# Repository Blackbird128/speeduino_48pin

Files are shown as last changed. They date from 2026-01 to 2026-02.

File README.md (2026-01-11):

# speeduino_48pin
Custom speeduino v0.4.4d hardware made to fit a standard housing with dual 24-pin Delphi connectors.

Simpler and lower cost alternative to the Speeduino Dropbear while keeping the same form factor and full compatibility with the Speeduino v0.4.4d hardware.

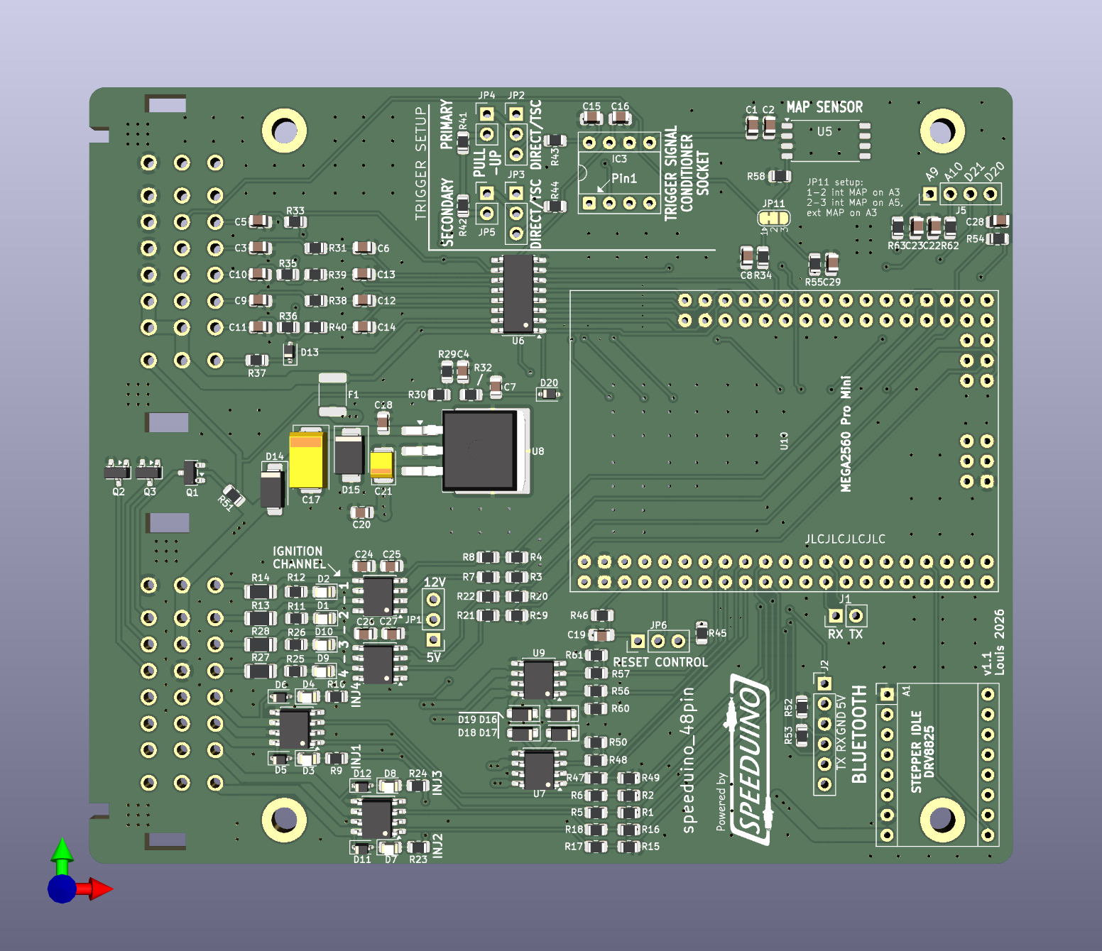
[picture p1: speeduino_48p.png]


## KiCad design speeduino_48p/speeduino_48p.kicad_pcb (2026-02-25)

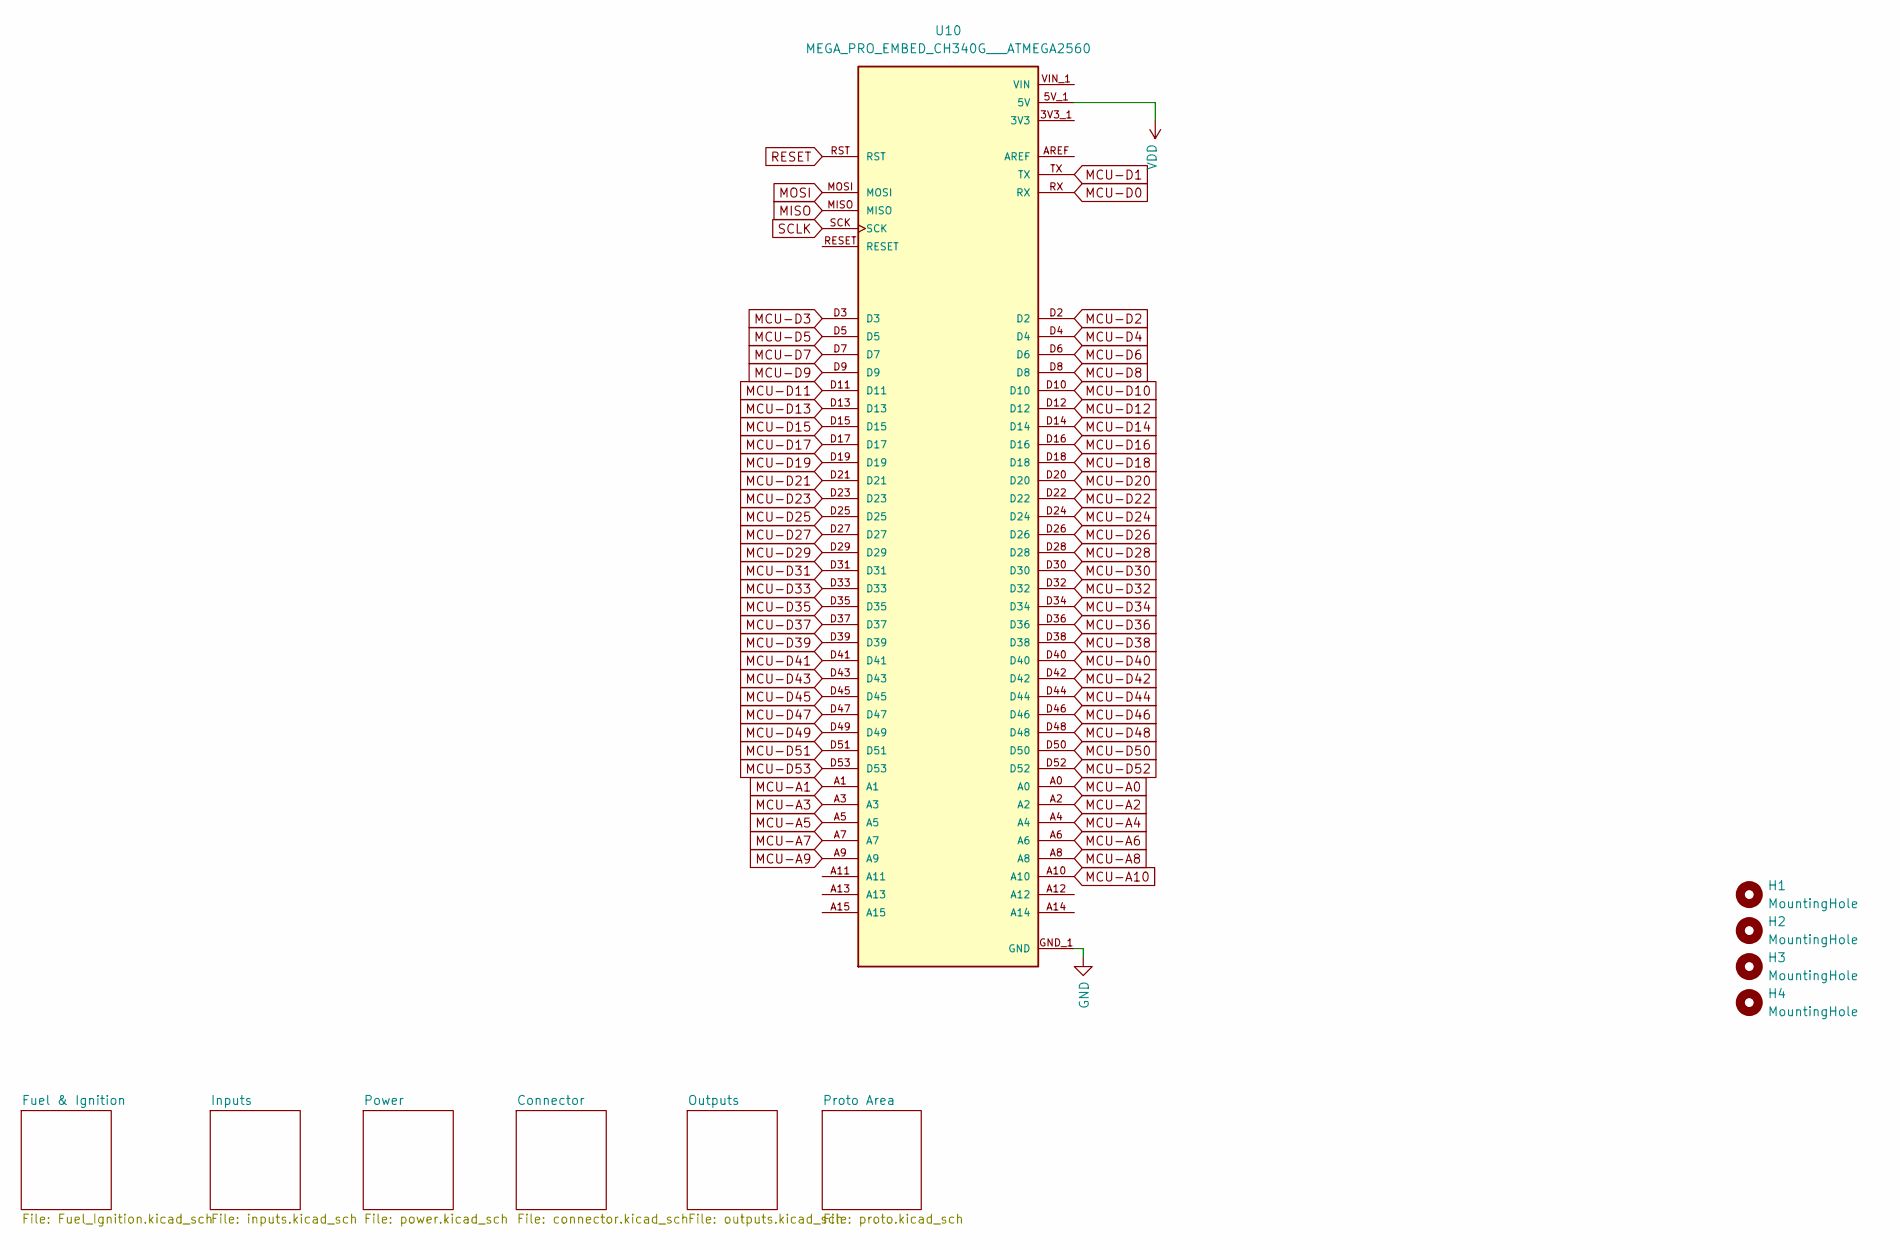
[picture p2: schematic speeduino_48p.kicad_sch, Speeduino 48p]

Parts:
H1, H2, H3, H4: MountingHole; MountingHole_3.2mm_M3_DIN965_Pad
U10: MEGA_PRO_EMBED_CH340G___ATMEGA2560; 2560ProMini; PARTREV 12/May/2017

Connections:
3V3: U10.3V3_1 (3V3), U10.3V3_2 (3V3)
ADC-Clamp-1: U10.A4; also elsewhere on the board
ADC-Clamp-2: U10.A3; also elsewhere on the board
ADC-Clamp-3: U10.A1; also elsewhere on the board
ADC-Clamp-4: U10.A2; also elsewhere on the board
ADC-Clamp-5: U10.A0; also elsewhere on the board
ADC-Clamp-6: U10.A8; also elsewhere on the board
ADC-Clamp-8: U10.D18; also elsewhere on the board
ADC-Clamp-9: U10.D19; also elsewhere on the board
ADC-Clamp-10: U10.D2; also elsewhere on the board
ADC-Clamp-13: U10.D51; also elsewhere on the board
GND: U10.GND_1 (GND), U10.GND_2 (GND), U10.GND_3 (GND); also elsewhere on the board
MCU-A5: U10.A5; also elsewhere on the board
MCU-A6: U10.A6
MCU-A7: U10.A7
MCU-A9: U10.A9; also elsewhere on the board
MCU-A10: U10.A10; also elsewhere on the board
MCU-D0: U10.RX; also elsewhere on the board
MCU-D1: U10.TX; also elsewhere on the board
MCU-D3: U10.D3; also elsewhere on the board
MCU-D4: U10.D4; also elsewhere on the board
MCU-D5: U10.D5; also elsewhere on the board
MCU-D6: U10.D6; also elsewhere on the board
MCU-D7: U10.D7; also elsewhere on the board
MCU-D8: U10.D8; also elsewhere on the board
MCU-D9: U10.D9; also elsewhere on the board
MCU-D10: U10.D10; also elsewhere on the board
MCU-D11: U10.D11; also elsewhere on the board
MCU-D12: U10.D12
MCU-D13: U10.D13
MCU-D14: U10.D14; also elsewhere on the board
MCU-D15: U10.D15; also elsewhere on the board
MCU-D16: U10.D16; also elsewhere on the board
MCU-D17: U10.D17; also elsewhere on the board
MCU-D20: U10.D20; also elsewhere on the board
MCU-D21: U10.D21; also elsewhere on the board
MCU-D22: U10.D22
MCU-D23: U10.D23
MCU-D24: U10.D24; also elsewhere on the board
MCU-D25: U10.D25
MCU-D26: U10.D26
MCU-D27: U10.D27
MCU-D28: U10.D28
MCU-D29: U10.D29
MCU-D30: U10.D30
MCU-D31: U10.D31
MCU-D32: U10.D32
MCU-D33: U10.D33
MCU-D34: U10.D34
MCU-D35: U10.D35
MCU-D36: U10.D36
MCU-D37: U10.D37
MCU-D38: U10.D38; also elsewhere on the board
MCU-D39: U10.D39
MCU-D40: U10.D40; also elsewhere on the board
MCU-D41: U10.D41
MCU-D42: U10.D42
MCU-D43: U10.D43
MCU-D44: U10.D44
MCU-D45: U10.D45; also elsewhere on the board
MCU-D46: U10.D46
MCU-D47: U10.D47; also elsewhere on the board
MCU-D48: U10.D48
MCU-D49: U10.D49; also elsewhere on the board
MCU-D50: U10.D50; also elsewhere on the board
MCU-D52: U10.D52; also elsewhere on the board
MCU-D53: U10.D53
MISO: U10.MISO
MOSI: U10.MOSI
RESET: U10.RST; also elsewhere on the board
SCLK: U10.SCK
VDD: U10.5V_1 (5V), U10.5V_2 (5V), U10.5V_3 (5V); also elsewhere on the board
VIN: U10.VIN_1 (VIN), U10.VIN_2 (VIN)

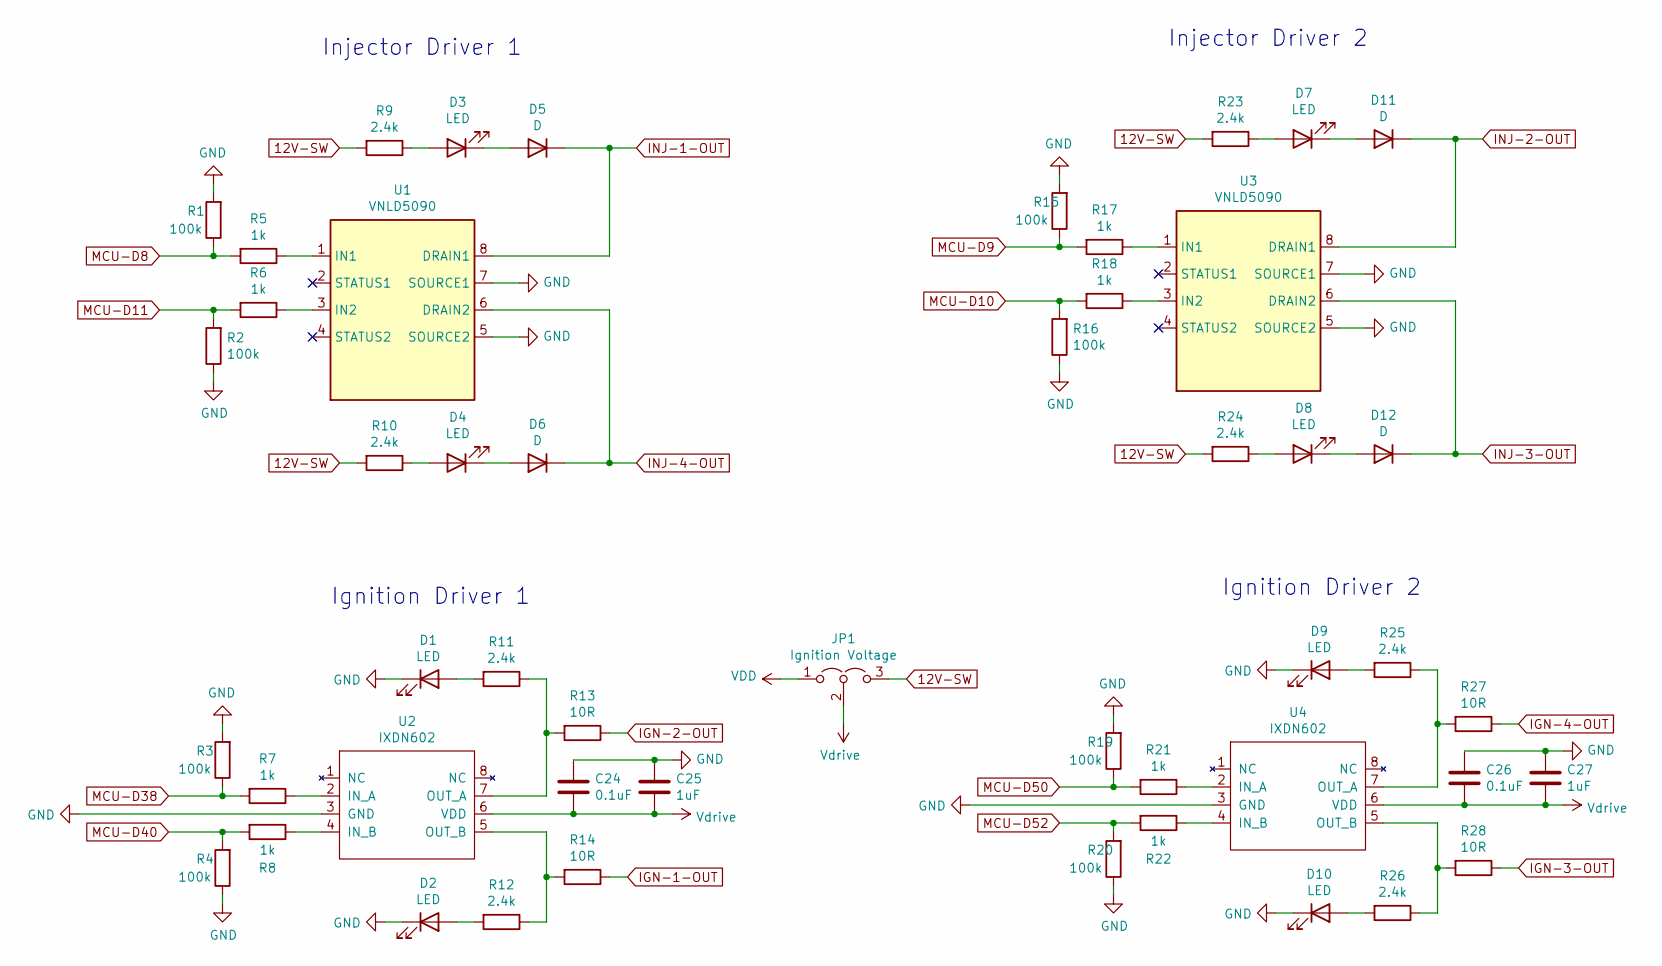
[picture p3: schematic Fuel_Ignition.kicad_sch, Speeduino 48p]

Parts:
C24, C26: 0.1uF; C_0805_2012Metric; Manufacturer_Part_Number CC0805KRX7R9BB104; Digikey Part Number 311-1140-1-ND
C25, C27: 1uF; C_0805_2012Metric; Manufacturer_Part_Number CC0805KKX7R7BB105; Digikey Part Number 311-1365-1-ND
D1, D2, D3, D4, D7, D8, D9, D10: LED; LED_0805_2012Metric; Manufacturer_Part_Number LH R974-LP-1; Digikey Part Number 475-1415-1-ND
D5, D6, D11, D12: D; D_SOD-323; Manufacturer_Part_Number 1N4448WX-TP; Digikey Part Number 1N4448WXTPMSCT-ND
JP1: Ignition Voltage; PinHeader_1x03_P2.54mm_Vertical; Manufacturer_Part_Number M20-9990345; Digikey Part Number 952-2263-ND
R1, R2, R3, R4, R15, R16, R19, R20: 100k; R_0805_2012Metric; Manufacturer_Part_Number RC0805FR-07100KL; Digikey Part Number 311-100KCRCT-ND
R5, R6, R7, R8, R17, R18, R21, R22: 1k; R_0805_2012Metric; Manufacturer_Part_Number RC0805FR-071KL; Digikey Part Number 311-1.00KCRCT-ND
R9, R10, R11, R12, R23, R24, R25, R26: 2.4k; R_0805_2012Metric; Manufacturer_Part_Number RC0805FR-072K4L; Digikey Part Number 311-2.40KCRCT-ND
R13, R14, R27, R28: 10R; R_1206_3216Metric; Manufacturer_Part_Number RC1206FR-0710RL; Digikey Part Number 311-10.0FRCT-ND
U1, U3: VNLD5090; SOIC-8_3.9x4.9mm_P1.27mm; Manufacturer_Part_Number VNLD5090-E; Digikey Part Number 497-18682-ND
U2, U4: IXDN602; SOIC-8_3.9x4.9mm_P1.27mm; Manufacturer_Part_Number IXDN602SIATR; Digikey Part Number 212-IXDN602SIACT-ND

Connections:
12V-SW: JP1.3 (B), R9.2, R10.2, R23.2, R24.2; also elsewhere on the board
GND: C24.1, C25.1, C26.1, C27.1, D1.1 (K), D2.1 (K), D9.1 (K), D10.1 (K), R1.2, R2.1, R3.2, R4.1, R15.2, R16.1, R19.2, R20.1, U1.5 (SOURCE2), U1.7 (SOURCE1), U2.3 (GND), U3.5 (SOURCE2), U3.7 (SOURCE1), U4.3 (GND); also elsewhere on the board
IGN-1-OUT: R14.1; also elsewhere on the board
IGN-2-OUT: R13.1; also elsewhere on the board
IGN-3-OUT: R28.1; also elsewhere on the board
IGN-4-OUT: R27.1; also elsewhere on the board
INJ-1-OUT: D5.1 (K), U1.8 (DRAIN1); also elsewhere on the board
INJ-2-OUT: D11.1 (K), U3.8 (DRAIN1); also elsewhere on the board
INJ-3-OUT: D12.1 (K), U3.6 (DRAIN2); also elsewhere on the board
INJ-4-OUT: D6.1 (K), U1.6 (DRAIN2); also elsewhere on the board
MCU-D8: R1.1, R5.2; also elsewhere on the board
MCU-D9: R15.1, R17.2; also elsewhere on the board
MCU-D10: R16.2, R18.2; also elsewhere on the board
MCU-D11: R2.2, R6.2; also elsewhere on the board
MCU-D38: R3.1, R7.2; also elsewhere on the board
MCU-D40: R4.2, R8.2; also elsewhere on the board
MCU-D50: R19.1, R21.2; also elsewhere on the board
MCU-D52: R20.2, R22.2; also elsewhere on the board
unnamed: D1.2 (A), R11.2
unnamed: D2.2 (A), R12.2
unnamed: D3.2 (A), R9.1
unnamed: D3.1 (K), D5.2 (A)
unnamed: D4.2 (A), R10.1
unnamed: D4.1 (K), D6.2 (A)
unnamed: D7.2 (A), R23.1
unnamed: D8.2 (A), R24.1
unnamed: D9.2 (A), R25.2
unnamed: D10.2 (A), R26.2
unnamed: D7.1 (K), D11.2 (A)
unnamed: D8.1 (K), D12.2 (A)
unnamed: R5.1, U1.1 (IN1)
unnamed: R6.1, U1.3 (IN2)
unnamed: R7.1, U2.2 (IN_A)
unnamed: R8.1, U2.4 (IN_B)
unnamed: R11.1, R13.2, U2.7 (OUT_A)
unnamed: R12.1, R14.2, U2.5 (OUT_B)
unnamed: R17.1, U3.1 (IN1)
unnamed: R18.1, U3.3 (IN2)
unnamed: R21.1, U4.2 (IN_A)
unnamed: R22.1, U4.4 (IN_B)
unnamed: R25.1, R27.2, U4.7 (OUT_A)
unnamed: R26.1, R28.2, U4.5 (OUT_B)
VDD: JP1.1 (A); also elsewhere on the board
Vdrive: C24.2, C25.2, C26.2, C27.2, JP1.2 (C), U2.6 (VDD), U4.6 (VDD)

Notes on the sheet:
Ignition Driver 2
Injector Driver 2
Injector Driver 1
Ignition Driver 1

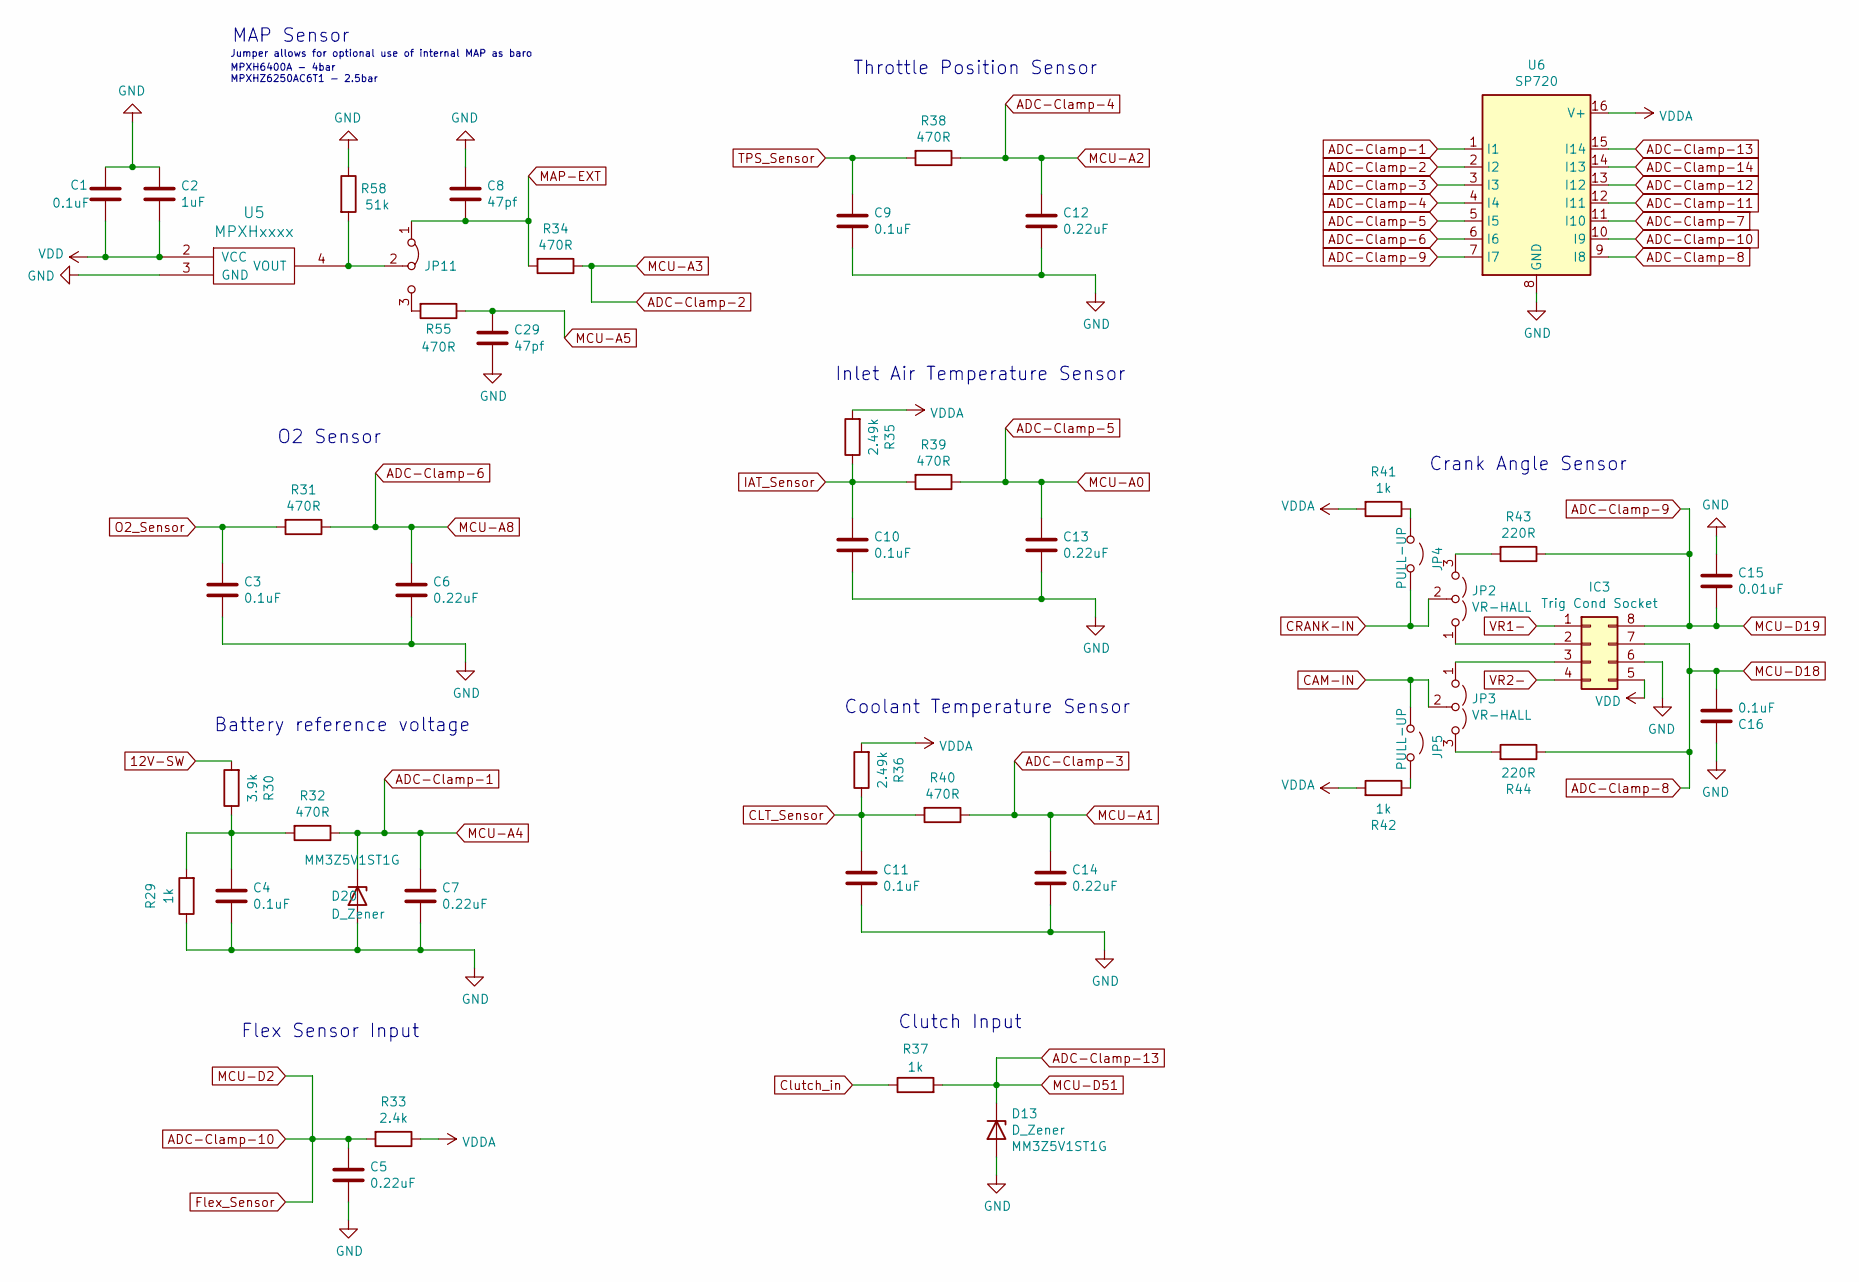
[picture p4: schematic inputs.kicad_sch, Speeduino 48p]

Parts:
C1: 0.1uF; C_0805_2012Metric; Manufacturer_Part_Number CC0805KRX7R9BB103; Digikey Part Number 311-1136-1-ND
C2: 1uF; C_0805_2012Metric; Manufacturer_Part_Number CC0805KKX7R7BB105; Digikey Part Number 311-1365-1-ND
C3, C4, C9, C10, C11, C16: 0.1uF; C_0805_2012Metric; Manufacturer_Part_Number CC0805KRX7R9BB104; Digikey Part Number 311-1140-1-ND
C5, C6, C7, C12, C13, C14: 0.22uF; C_0805_2012Metric; Manufacturer_Part_Number CL21B224KOCNNNC; Digikey Part Number 1276-1284-1-ND
C8, C29: 47pf; C_0805_2012Metric; Manufacturer_Part_Number CC0805KRX7R9BB471; Digikey Part Number 311-1124-1-ND
C15: 0.01uF; C_0805_2012Metric; Manufacturer_Part_Number CC0805KRX7R9BB103; Digikey Part Number 311-1136-1-ND
D13, D20: D_Zener; D_SOD-323; Part # MM3Z5V1ST1G; Digikey Part Number MM3Z5V1ST1GOSCT-ND
IC3: Trig Cond Socket; DIP-8_W7.62mm_Socket
JP2, JP3: VR-HALL; PinHeader_1x03_P2.54mm_Vertical; Manufacturer_Part_Number M20-9990345; Digikey Part Number 952-2263-ND
JP4, JP5: PULL-UP; PinHeader_1x02_P2.54mm_Vertical; Manufacturer_Part_Number M20-9990245; Digikey Part Number 952-2261-ND
JP11: Jumper_3_Bridged12; SolderJumper-3_P1.3mm_Bridged12_RoundedPad1.0x1.5mm
R29, R37, R41, R42: 1k; R_0805_2012Metric; Manufacturer_Part_Number RC0805FR-071KL; Digikey Part Number 311-1.00KCRCT-ND
R30: 3.9k; R_0805_2012Metric; Manufacturer_Part_Number RC0805FR-073K9L; Digikey Part Number 311-3.90KCRCT-ND
R31, R32, R34, R38, R39, R40, R55: 470R; R_0805_2012Metric; Manufacturer_Part_Number ERJ-6ENF4700V; Digikey Part Number P470CCT-ND
R33: 2.4k; R_0805_2012Metric; Manufacturer_Part_Number RC0805FR-072K4L; Digikey Part Number 311-2.40KCRCT-ND
R35, R36: 2.49k; R_0805_2012Metric; Manufacturer_Part_Number RT0805BRD072K49L; Digikey Part Number YAG1854CT-ND
R43, R44: 220R; R_0805_2012Metric; Manufacturer_Part_Number RC0805FR-07220RL; Digikey Part Number 311-220CRCT-ND
R58: 51k; R_0805_2012Metric; Manufacturer_Part_Number ERJ-6ENF4700V; Digikey Part Number P470CCT-ND
U5: MPXHxxxx; SOP-8_3.76x4.96mm_P1.27mm; Manufacturer_Part_Number MPXH6400A; Digikey Part Number MPXH6400A
U6: SP720; SOIC-16_3.9x9.9mm_P1.27mm; Manufacturer_Part_Number SP720ABTG; Digikey Part Number F3162CT-ND

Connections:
12V-SW: R30.2; also elsewhere on the board
ADC-Clamp-1: C7.1, D20.1 (K), R32.1, U6.1 (I1); also elsewhere on the board
ADC-Clamp-2: R34.1, U6.2 (I2); also elsewhere on the board
ADC-Clamp-3: C14.1, R40.1, U6.3 (I3); also elsewhere on the board
ADC-Clamp-4: C12.1, R38.1, U6.4 (I4); also elsewhere on the board
ADC-Clamp-5: C13.1, R39.1, U6.5 (I5); also elsewhere on the board
ADC-Clamp-6: C6.1, R31.1, U6.6 (I6); also elsewhere on the board
ADC-Clamp-7: U6.11 (I10)
ADC-Clamp-8: C16.2, IC3.7, R44.1, U6.9 (I8); also elsewhere on the board
ADC-Clamp-9: C15.2, IC3.8, R43.1, U6.7 (I7); also elsewhere on the board
ADC-Clamp-10: C5.1, R33.2, U6.10 (I9); also elsewhere on the board
ADC-Clamp-11: U6.12 (I11)
ADC-Clamp-12: U6.13 (I12)
ADC-Clamp-13: D13.1 (K), R37.2, U6.15 (I14); also elsewhere on the board
ADC-Clamp-14: U6.14 (I13)
CAM-IN: JP3.2 (C), JP5.1 (A); also elsewhere on the board
CLT_Sensor: C11.1, R36.1, R40.2; also elsewhere on the board
CRANK-IN: JP2.2 (C), JP4.1 (A); also elsewhere on the board
Clutch_in: R37.1; also elsewhere on the board
GND: C1.1, C2.1, C3.2, C4.2, C5.2, C6.2, C7.2, C8.1, C9.2, C10.2, C11.2, C12.2, C13.2, C14.2, C15.1, C16.1, C29.2, D13.2 (A), D20.2 (A), IC3.6, R29.1, R58.1, U5.3 (GND), U6.8 (GND); also elsewhere on the board
IAT_Sensor: C10.1, R35.1, R39.2; also elsewhere on the board
MAP-EXT: C8.2, JP11.1 (A), R34.2; also elsewhere on the board
MCU-A5: C29.1, R55.1; also elsewhere on the board
unnamed: C4.1, R29.2, R30.1, R32.2
unnamed: IC3.2, JP2.1 (A)
unnamed: IC3.3, JP3.1 (A)
unnamed: JP2.3 (B), R43.2
unnamed: JP3.3 (B), R44.2
unnamed: JP4.2 (B), R41.1
unnamed: JP5.2 (B), R42.1
unnamed: JP11.3 (B), R55.2
unnamed: JP11.2 (C), R58.2, U5.4 (VOUT)
O2_Sensor: C3.1, R31.2; also elsewhere on the board
TPS_Sensor: C9.1, R38.2; also elsewhere on the board
VDD: C1.2, C2.2, IC3.5, U5.2 (VCC); also elsewhere on the board
VDDA: R33.1, R35.2, R36.2, R41.2, R42.2, U6.16 (V+); also elsewhere on the board
VR1-: IC3.1; also elsewhere on the board
VR2-: IC3.4; also elsewhere on the board

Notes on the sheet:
Clutch Input
MPXH6400A - 4bar MPXHZ6250AC6T1 - 2.5bar
O2 Sensor
Coolant Temperature Sensor
Inlet Air Temperature Sensor
MAP Sensor
Battery reference voltage
Crank Angle Sensor
Throttle Position Sensor
Flex Sensor Input
Jumper allows for optional use of internal MAP as baro

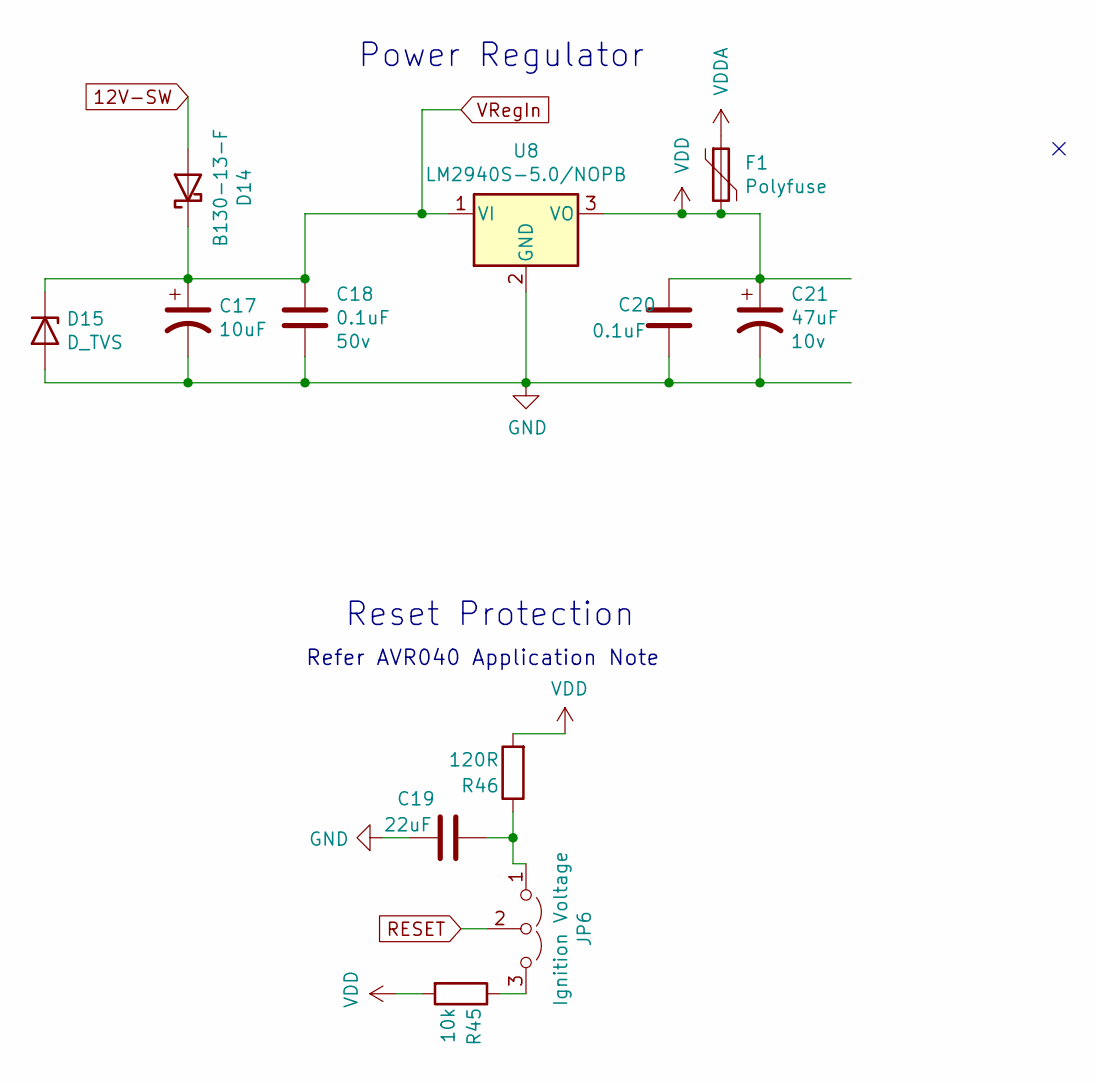
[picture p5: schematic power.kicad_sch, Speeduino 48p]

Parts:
C17: 10uF; CP_EIA-7343-31_Kemet-D; Voltage 35v; Manufacturer_Part_Number T491D106K050AT; Digikey Part Number 399-8361-1-ND
C18: 0.1uF; C_0805_2012Metric; Voltage 50v; Manufacturer_Part_Number CC0805KRX7R9BB104; Digikey Part Number 311-1140-1-ND
C19: 22uF; C_0805_2012Metric_Pad1.18x1.45mm_HandSolder; Manufacturer_Part_Number CL21A226KQCLRNC; Digikey Part Number 1276-6687-1-ND
C20: 0.1uF; C_0805_2012Metric; Manufacturer_Part_Number CC0805KRX7R9BB104; Digikey Part Number 311-1140-1-ND
C21: 47uF; CP_EIA-3528-21_Kemet-B; Voltage 10v; Manufacturer_Part_Number TAJB476K006RNJ; Digikey Part Number 478-1692-1-ND
D14: B130-13-F; D_SMA; Manufacturer_Part_Number B130-13-F; Digikey Part Number B130-FDICT-ND
D15: D_TVS; D_SMB; Manufacturer_Part_Number SMBJ40A-Q; Digikey Part Number SMBJ40A-QCT-ND
F1: Polyfuse; Fuse_1812_4532Metric; Manufacturer_Part_Number 0ZCC0050FF2C; Digikey Part Number 507-1361-1-ND
JP6: Ignition Voltage; PinHeader_1x03_P2.54mm_Vertical; Manufacturer_Part_Number M20-9990345; Digikey Part Number 952-2263-ND
R45: 10k; R_0805_2012Metric; Manufacturer_Part_Number RC0805JR-0710KL; Digikey Part Number 311-10KARCT-ND
R46: 120R; R_0805_2012Metric; Manufacturer_Part_Number RC0805FR-07120RL; Digikey Part Number 311-120CRCT-ND
U8: LM2940S-5.0/NOPB; TO-263-3_TabPin2; Manufacturer_Part_Number LM2940S-5.0/NOPB; Digikey Part Number LM2940S-5.0/NOPB-ND

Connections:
12V-SW: D14.2 (A); also elsewhere on the board
GND: C17.2, C18.2, C19.2, C20.2, C21.2, D15.2 (A), U8.2 (GND); also elsewhere on the board
unnamed: C19.1, JP6.1 (A), R46.1
unnamed: JP6.3 (B), R45.1
RESET: JP6.2 (C); also elsewhere on the board
VDD: C20.1, C21.1, F1.2, R45.2, R46.2, U8.3 (VO); also elsewhere on the board
VDDA: F1.1; also elsewhere on the board
VRegIn: C17.1, C18.1, D14.1 (K), D15.1 (K), U8.1 (VI)

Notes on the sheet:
Reset Protection
Power Regulator
Refer AVR040 Application Note

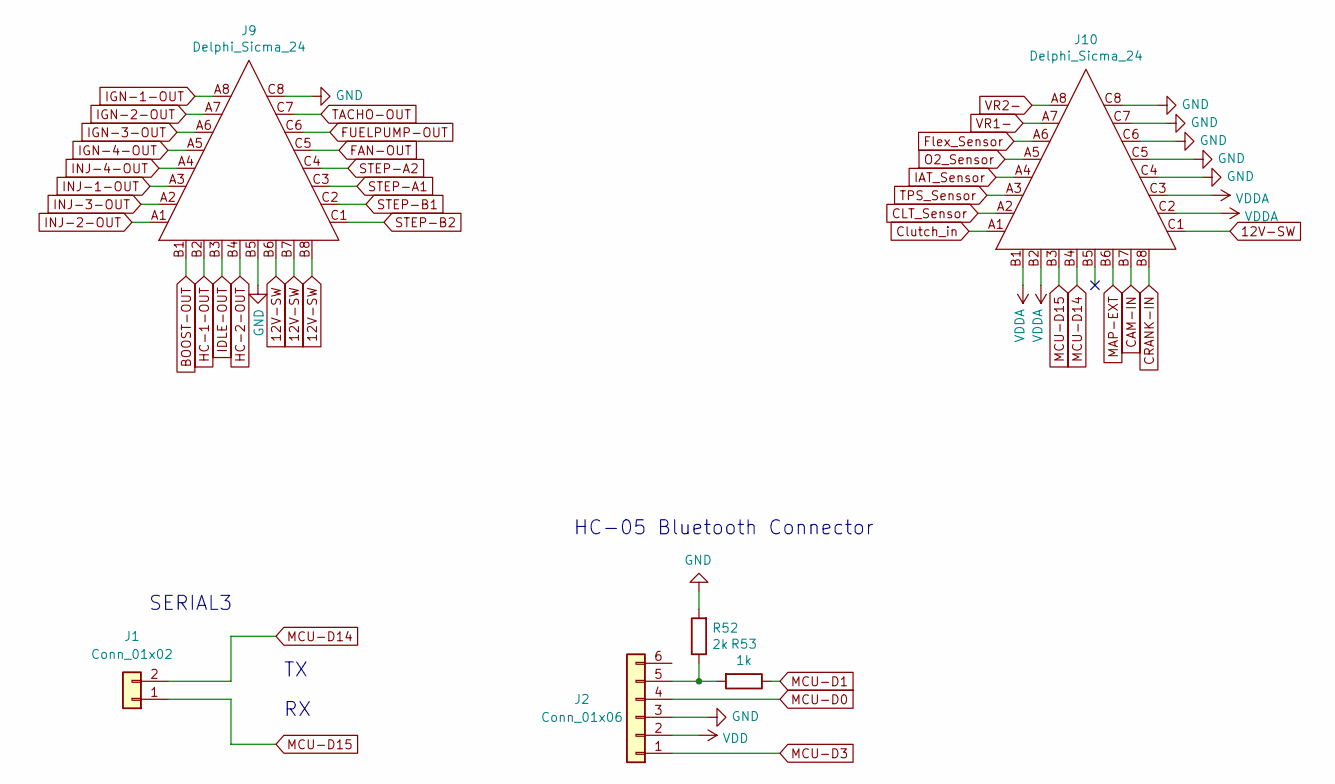
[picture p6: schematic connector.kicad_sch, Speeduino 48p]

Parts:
J1: Conn_01x02; PinHeader_1x02_P2.54mm_Vertical
J2: Conn_01x06; PinHeader_1x06_P2.54mm_Vertical
J9: Delphi_Sicma_24; Delphi_Sicma_24_Grey
J10: Delphi_Sicma_24; Delphi_Sicma_24_Black
R52: 2k; R_0805_2012Metric; Manufacturer_Part_Number RC0805FR-072KL; Digikey Part Number 311-2.00KCRCT-ND
R53: 1k; R_0805_2012Metric; Manufacturer_Part_Number RC0805FR-071KL; Digikey Part Number 311-1.00KCRCT-ND

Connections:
12V-SW: J9.B6, J9.B7, J9.B8, J10.C1; also elsewhere on the board
ADC-Clamp-10: J10.A6; also elsewhere on the board
BOOST-OUT: J9.B1; also elsewhere on the board
CAM-IN: J10.B7; also elsewhere on the board
CLT_Sensor: J10.A2; also elsewhere on the board
CRANK-IN: J10.B8; also elsewhere on the board
Clutch_in: J10.A1; also elsewhere on the board
FAN-OUT: J9.C5; also elsewhere on the board
FUELPUMP-OUT: J9.C6; also elsewhere on the board
GND: J2.3, J9.B5, J9.C8, J10.C4, J10.C5, J10.C6, J10.C7, J10.C8, R52.2; also elsewhere on the board
HC-1-OUT: J9.B2; also elsewhere on the board
HC-2-OUT: J9.B4; also elsewhere on the board
IAT_Sensor: J10.A4; also elsewhere on the board
IDLE-OUT: J9.B3; also elsewhere on the board
IGN-1-OUT: J9.A8; also elsewhere on the board
IGN-2-OUT: J9.A7; also elsewhere on the board
IGN-3-OUT: J9.A6; also elsewhere on the board
IGN-4-OUT: J9.A5; also elsewhere on the board
INJ-1-OUT: J9.A3; also elsewhere on the board
INJ-2-OUT: J9.A1; also elsewhere on the board
INJ-3-OUT: J9.A2; also elsewhere on the board
INJ-4-OUT: J9.A4; also elsewhere on the board
MAP-EXT: J10.B6; also elsewhere on the board
MCU-D0: J2.4; also elsewhere on the board
MCU-D1: R53.1; also elsewhere on the board
MCU-D3: J2.1; also elsewhere on the board
MCU-D14: J1.2, J10.B4; also elsewhere on the board
MCU-D15: J1.1, J10.B3; also elsewhere on the board
unnamed: J2.5, R52.1, R53.2
O2_Sensor: J10.A5; also elsewhere on the board
STEP-A1: J9.C3; also elsewhere on the board
STEP-A2: J9.C4; also elsewhere on the board
STEP-B1: J9.C2; also elsewhere on the board
STEP-B2: J9.C1; also elsewhere on the board
TACHO-OUT: J9.C7; also elsewhere on the board
TPS_Sensor: J10.A3; also elsewhere on the board
VDD: J2.2; also elsewhere on the board
VDDA: J10.B1, J10.B2, J10.C2, J10.C3; also elsewhere on the board
VR1-: J10.A7; also elsewhere on the board
VR2-: J10.A8; also elsewhere on the board

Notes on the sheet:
SERIAL3
HC-05 Bluetooth Connector

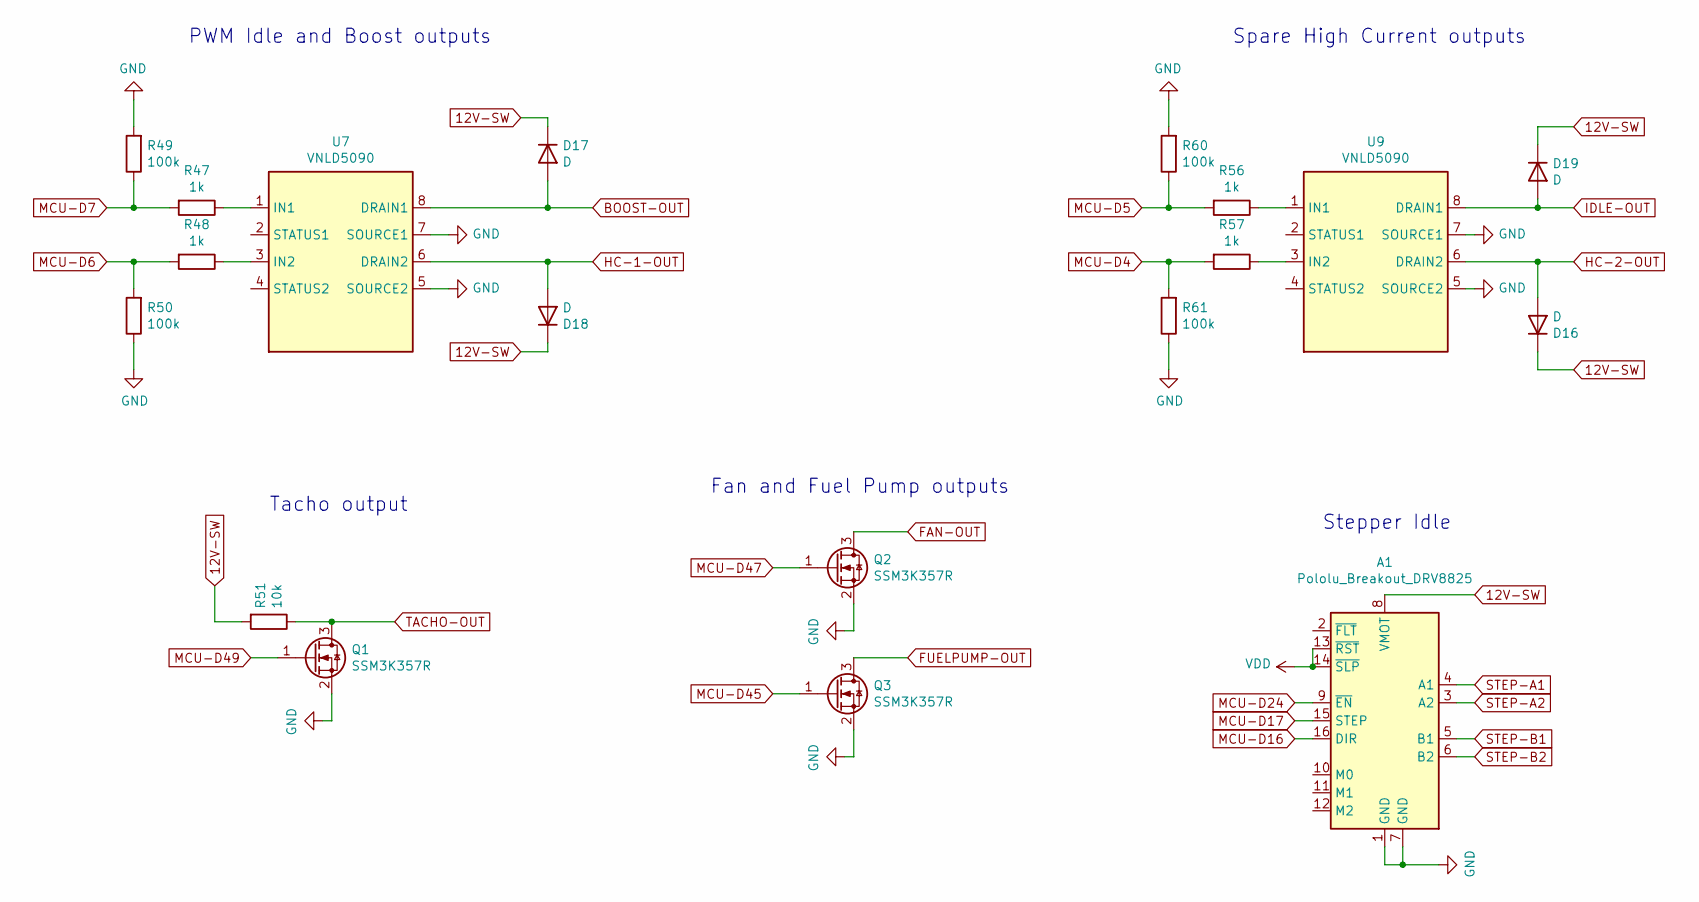
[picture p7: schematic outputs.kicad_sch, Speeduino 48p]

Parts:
A1: Pololu_Breakout_DRV8825; Pololu_Breakout-16_15.2x20.3mm
D16, D17, D18, D19: D; D_SOD-123F; Manufacturer_Part_Number S110FA; Digikey Part Number S110FACT-ND
Q1, Q2, Q3: SSM3K357R; SOT-23; Manufacturer_Part_Number SSM3K357R; Digikey Part Number SSM3K357RLFCT-ND
R47, R48, R56, R57: 1k; R_0805_2012Metric; Manufacturer_Part_Number RC0805FR-071KL; Digikey Part Number 311-1.00KCRCT-ND
R49, R50, R60, R61: 100k; R_0805_2012Metric; Manufacturer_Part_Number RC0805FR-07100KL; Digikey Part Number 311-100KCRCT-ND
R51: 10k; R_0805_2012Metric; Manufacturer_Part_Number RC0805JR-0710KL; Digikey Part Number 311-10KARCT-ND
U7, U9: VNLD5090; SOIC-8_3.9x4.9mm_P1.27mm; Manufacturer_Part_Number VNLD5090-E; Digikey Part Number 497-18682-ND

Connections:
12V-SW: A1.8 (VMOT), D16.1 (K), D17.1 (K), D18.1 (K), D19.1 (K), R51.2; also elsewhere on the board
BOOST-OUT: D17.2 (A), U7.8 (DRAIN1); also elsewhere on the board
FAN-OUT: Q2.3 (D); also elsewhere on the board
FUELPUMP-OUT: Q3.3 (D); also elsewhere on the board
GND: A1.1 (GND), A1.7 (GND), Q1.2 (S), Q2.2 (S), Q3.2 (S), R49.2, R50.1, R60.2, R61.1, U7.5 (SOURCE2), U7.7 (SOURCE1), U9.5 (SOURCE2), U9.7 (SOURCE1); also elsewhere on the board
HC-1-OUT: D18.2 (A), U7.6 (DRAIN2); also elsewhere on the board
HC-2-OUT: D16.2 (A), U9.6 (DRAIN2); also elsewhere on the board
IDLE-OUT: D19.2 (A), U9.8 (DRAIN1); also elsewhere on the board
MCU-D4: R57.2, R61.2; also elsewhere on the board
MCU-D5: R56.2, R60.1; also elsewhere on the board
MCU-D6: R48.2, R50.2; also elsewhere on the board
MCU-D7: R47.2, R49.1; also elsewhere on the board
MCU-D16: A1.16 (DIR); also elsewhere on the board
MCU-D17: A1.15 (STEP); also elsewhere on the board
MCU-D24: A1.9 (~EN); also elsewhere on the board
MCU-D45: Q3.1 (G); also elsewhere on the board
MCU-D47: Q2.1 (G); also elsewhere on the board
MCU-D49: Q1.1 (G); also elsewhere on the board
unnamed: R47.1, U7.1 (IN1)
unnamed: R48.1, U7.3 (IN2)
unnamed: R56.1, U9.1 (IN1)
unnamed: R57.1, U9.3 (IN2)
STEP-A1: A1.4 (A1); also elsewhere on the board
STEP-A2: A1.3 (A2); also elsewhere on the board
STEP-B1: A1.5 (B1); also elsewhere on the board
STEP-B2: A1.6 (B2); also elsewhere on the board
TACHO-OUT: Q1.3 (D), R51.1; also elsewhere on the board
VDD: A1.13 (~RST), A1.14 (~SLP); also elsewhere on the board

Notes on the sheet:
Spare High Current outputs
Stepper Idle
PWM Idle and Boost outputs
Fan and Fuel Pump outputs
Tacho output

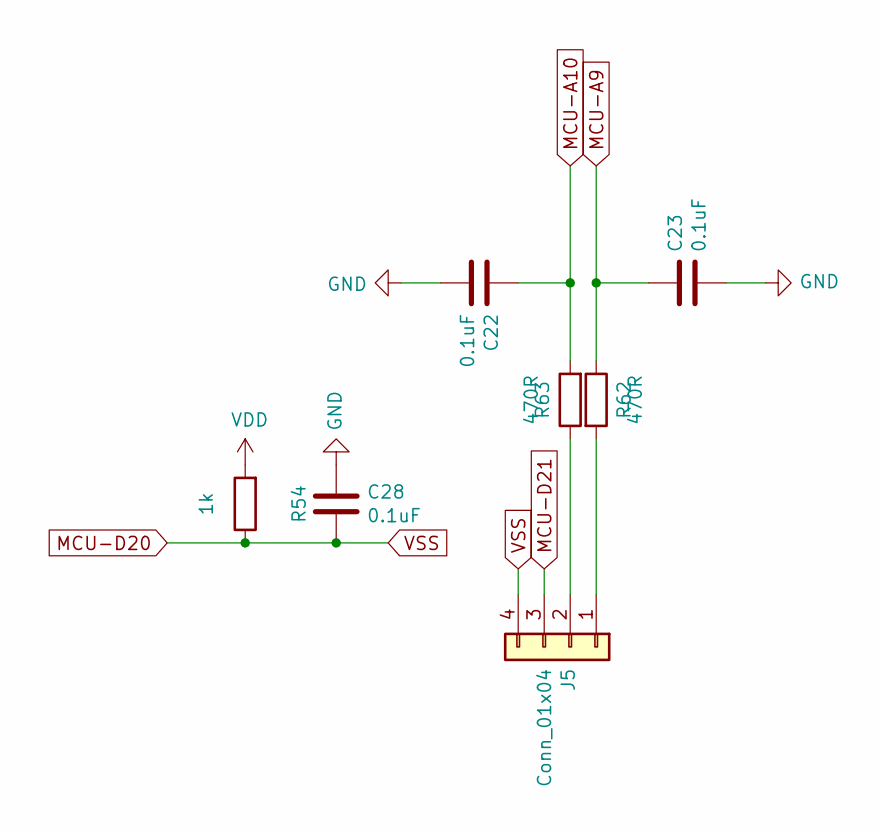
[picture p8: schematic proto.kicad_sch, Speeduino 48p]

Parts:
C22, C23, C28: 0.1uF; C_0805_2012Metric; Manufacturer_Part_Number CC0805KRX7R9BB104; Digikey Part Number 311-1140-1-ND
J5: Conn_01x04; PinHeader_1x04_P2.54mm_Vertical
R54: 1k; R_0805_2012Metric; Manufacturer_Part_Number RC0805FR-071KL; Digikey Part Number 311-1.00KCRCT-ND
R62, R63: 470R; R_0805_2012Metric; Manufacturer_Part_Number ERJ-6ENF4700V; Digikey Part Number P470CCT-ND

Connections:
GND: C22.2, C23.2, C28.1; also elsewhere on the board
MCU-A9: C23.1, R63.1; also elsewhere on the board
MCU-A10: C22.1, R62.2; also elsewhere on the board
MCU-D20: C28.2, J5.4, R54.1; also elsewhere on the board
MCU-D21: J5.3; also elsewhere on the board
unnamed: J5.1, R63.2
unnamed: J5.2, R62.1
VDD: R54.2; also elsewhere on the board

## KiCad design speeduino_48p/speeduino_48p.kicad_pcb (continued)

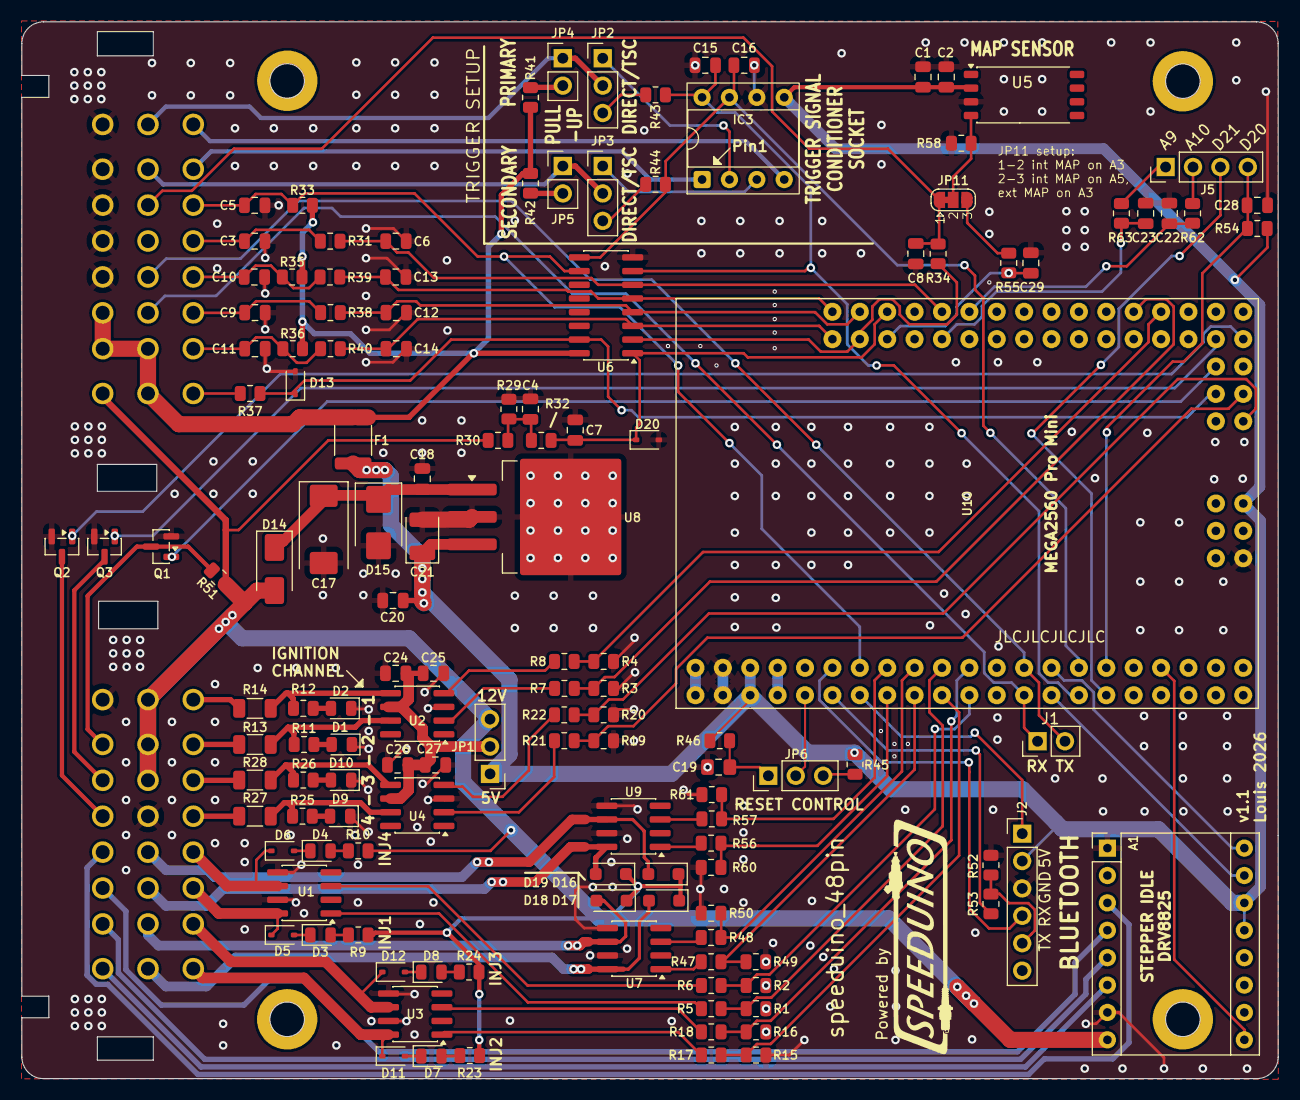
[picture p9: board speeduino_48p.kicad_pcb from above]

Board: 2 copper layers, 116.5 x 98.0 mm, 143 parts (0 on the bottom side), 118 nets.
